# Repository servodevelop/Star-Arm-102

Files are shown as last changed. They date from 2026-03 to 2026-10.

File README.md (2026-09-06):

# Star Arm 102: Open-Source Robotic Arm Development Resources
[中文](README.zh.md)

## Ecosystem

Star-Arm-102 is the central repository for Fashion Star's Star Arm 102 robotic arm ecosystem, bringing together teleoperation, ROS 2, LeRobot integrations, and hardware resources.

- 🔗 [Star Arm 102 Series Hub](https://fashionstar.com.hk/robot-arm/star-arm-102/)
- 🐙 [Main Repo: Star-Arm-102](https://github.com/servodevelop/Star-Arm-102)

## Related Repositories

- [piper-mate](https://github.com/servodevelop/piper-mate) — Main repository for the PiPER-Mate robotic arm project and its teleoperation workflows.
- [lerobot](https://github.com/servodevelop/lerobot) — Fashion Star's LeRobot framework integration fork for robotic arm learning and teleoperation.
- [servo-canbus-sdk](https://github.com/servodevelop/servo-canbus-sdk) — CAN bus servo SDK with Python examples for Fashion Star CAN bus servos.
- [servo-uart-rs485-sdk](https://github.com/servodevelop/servo-uart-rs485-sdk) — UART/RS485 servo SDK with serial-bus examples and development tools.
- [Star Arm 102 Series Hub](https://fashionstar.com.hk/robot-arm/star-arm-102/) — Official series overview and product information.







---

## 📖 Project Overview

<p align="center">
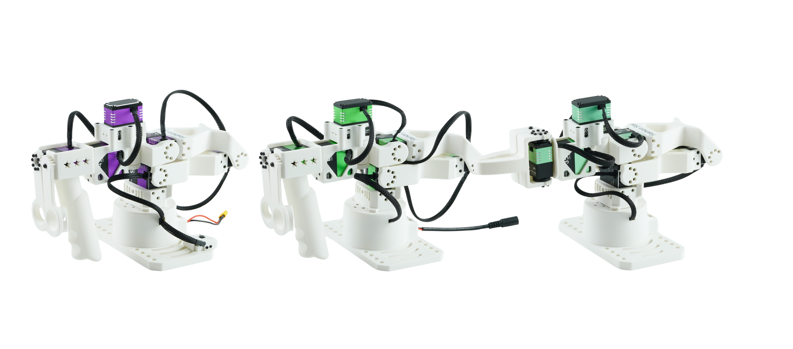
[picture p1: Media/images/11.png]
  
</p>

Star Arm 102 is an open-source 6+1 DOF leader–follower robotic arm system for teleoperation and robotics development. This repository brings together the code and resources needed to work with it, including Python SDK examples, ROS 2 Humble packages, LeRobot integrations, hardware files, and setup guides.

Use it to connect and control the arms, try supported software workflows, and build your own robotics applications.

Learn more about the full Star Arm 102 series:
[Star Arm 102 robot arm — series overview](https://fashionstar.com.hk/robot-arm/star-arm-102/)

## 🛒 Where to Buy
- [Star Arm 102-LD — LeRobot Certified Leader Arm](https://fashionstar.com.hk/store/product/star-arm-102-ld/)
- [Star Arm 102-HD — Pose-Holding Leader Arm](https://fashionstar.com.hk/store/product/star-arm-102-hd/)
- [Star Arm 102-FL — Follower Arm](https://fashionstar.com.hk/store/product/star-arm-102-fl/)

## 🔗 Related Links
- [Fashion Star Official Website](https://fashionstar.com.hk/)

### ✨ Key Features

- 🔓 **Open source · Low cost · Flexible access**

Fully open-source design lowers the barrier to learning and use.

Two access options are available: purchase a pre-assembled unit for immediate use, or print and assemble it yourself by preparing the printed parts and components. The DIY option is well suited for teaching and hands-on practice.

- ⚙️ **Well-designed robotic arm configuration**

6 active joints + 1 end effector.

The joint configuration strictly satisfies the Pieper criterion and supports analytical inverse kinematics. The algorithm is transparent, making it easy to teach and extend.

- 🔗 **LD model: highly compatible teleoperation leader arm**

Star Arm 102-LD can smoothly teleoperate the FL model in the same series.

It is also directly compatible with reBot and other robotic arms that have identical or similar kinematic configurations.

One leader arm can work with multiple arms, providing a smoother teleoperation experience across different systems.

- 🔒 **HD model: enhanced leader arm with one-button locking**

Star Arm 102-HD is an upcoming leader-arm model in the Star Arm 102 series.

Compared with the LD model, HD adds a one-button locking function: after the lock button is pressed, the leader arm holds its current pose and the follower arm enters the locked state at the same time; pressing the button again unlocks the system.

- 🕹️ **Multi-platform compatibility · Plug and play**

Supports direct teleoperation through the Python SDK.

Deeply compatible with the LeRobot and ROS 2 ecosystems.

Covers the full workflow of real robotic applications: data collection → simulation → model training → physical deployment.

- 📚 **Complete learning resources**

Provides tutorials, API documentation, and example code from beginner to advanced levels.

Suitable for university teaching, research experiments, and self-learning by individual developers.

---

## 🔧 Arm Specifications

| | Star Arm 102-HD | Star Arm 102-LD | Star Arm 102-FL |
|---|---|---|---|
| Arm span | 420mm | 420mm | 420mm |
| DOF | 6+1 | 6+1 | 6+1 |
| Repeatability | - | - | ±0.5mm |
| Suggested maximum payload | - | - | 500g |
| Joint range<br> | Joint 1: ±110°<br>Joint 2: 0°\~180°<br>Joint 3: 0°\~270°<br>Joint 4: ±90°<br>Joint 5: ±65°<br>Joint 6: ±150°<br>Handle: 0\~90° | Joint 1: ±110°<br>Joint 2: 0°\~180°<br>Joint 3: 0°\~270°<br>Joint 4: ±90°<br>Joint 5: ±65°<br>Joint 6: ±150°<br>Handle: 0\~90° | Joint 1: ±110°<br>Joint 2: 0°\~180°<br>Joint 3: 0°\~270°<br>Joint 4: ±90°<br>Joint 5: ±65°<br>Joint 6: ±150°<br>Gripper: 0\~90° |
| Servo configuration | Joints 1-4 (servo IDs 0-3): RP8-U45H-M;<br>Joint 5 (servo ID 4): RP8-U45H-M-C029;<br>Joint 6 and handle joint (servo IDs 5-6): RP8-U45H-M-C028; | Joints 1-4 (servo IDs 0-3): RA8-U01H-M;<br>Joint 5 (servo ID 4): RA8-U02H-M;<br>Joint 6 and handle joint (servo IDs 5-6): RA8-U03H-M; | Joints 1, 4, 7, and gripper joint (servo IDs 0, 3, 6): RA8-U35H-M;<br>Joints 2 and 3 (servo IDs 1-2): RX8-U50H-M;<br>Joint 5 (servo ID 4): RA8-U27H-M-C005;<br>Joint 6 (servo ID 5): RA8-U35H-M-C047; |
| Communication hub | UC-01 | UC-01 | UC-01 |
| Communication method | UART | UART | UART |
| Power supply | 12V10A / XT30 | 12V3A / DC5521 | 12V10A / XT30 |
| Accessories | Screws, threadlocker, woodworking clamps x2, spare PCB (UC01), DC power adapter cable (5.5×2.1mm connector), 200mm servo extension cable, USB-A to USB-C cable, mouse pad, base support | Screws, threadlocker, woodworking clamps x2, spare PCB (UC01), XT30 power adapter cable, 200mm servo extension cable, USB-A to USB-C cable, mouse pad, base support | Screws, threadlocker, woodworking clamps x2, spare PCB (UC01), DC power adapter cable (5.5×2.1mm connector), 200mm servo extension cable, USB-A to USB-C cable, mouse pad |
| Encoder | 12-bit magnetic encoder | 12-bit magnetic encoder | 12-bit magnetic encoder |
| Weight | 883g | 721g | 791g |
| Recommended operating temperature | 0-40°C | 0-40°C | 0-40°C |
| Button lock support | ✓ | × | - |
| LeRobot support | ✓ | ✓ | ✓ |
| ROS 2 support | ✓ | ✓ | ✓ |
| MoveIt support | - | - | ✓ |
| Gazebo support | - | - | ✓ |

---

## 🔧 Hardware Resources

<p align="center">
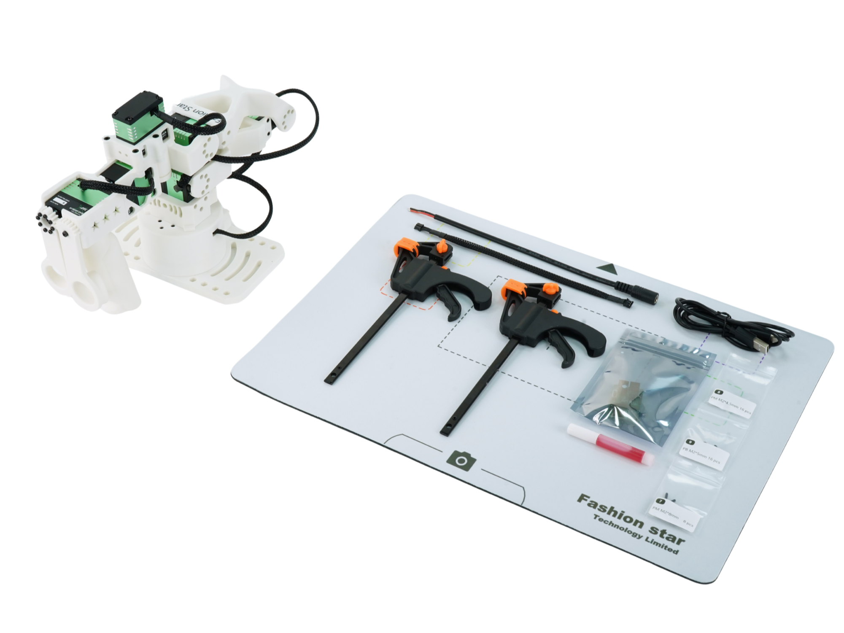
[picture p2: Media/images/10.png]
  
</p>

- [Parts List](./Hardware/README.md): view the complete parts list, quantities, and accessories

- [Engineering Drawings](./Hardware/cad/README.md): view assembly drawings and manufacturing drawings

- [Assembly Guide](./Hardware/assembly/README.md): view assembly sequence, notes, and reference images. This section is still being improved.

- [MakerWorld Models](https://makerworld.com.cn/zh/models/2366043-xing-bi-102-ld?from=search#profileId-2682765): download the 3D printable files for Star Arm 102-LD, which can be used to replace parts or assemble the robotic arm yourself

> The firmware and documentation for the Star Arm 102-HD lock-button board are located in the `Star-Arm-102-dev-main` project. The button board uses ID 7 by default. In host mode, it can directly send lock / unlock commands. In slave mode, it can be polled by the host as a simulated servo and returns 0.0° / 180.0° to indicate unlocked / locked states.

---

## 🚀 Quick Start

### Requirements

| Item | Requirement |
|---|---|
| Operating System | Ubuntu 22.04 |
| ROS Version | ROS 2 Humble |
| Hardware | StarArm 102 robotic arms (Leader/HD + Follower) |
| Driver | [CH340 USB Driver](https://www.wch.cn/downloads/CH341SER_EXE.html) |

### Installation

#### Method 1: Bare-metal teleoperation with Python SDK (recommended for beginners)

```bash
# 1. Install dependencies
pip install pyserial fashionstar-uart-sdk

# 2. Run the program
sudo chmod 777 /dev/ttyUSB*
python3 ./Python_SDK/stararm102_ro.py
```

#### Method 2: ROS 2 Humble

```bash
# See ROS2_HUMBLE/README.md for configuration instructions
```

#### Method 3: LeRobot framework

```bash
# See Lerobot/README.md for configuration instructions
```

---

## 📂 Project Structure

<details>
<summary>Expand to view the project structure</summary>

```text
Star-Arm-102/
|-- .gitignore                               # Git ignore rules
|-- Hardware/                                # Hardware resources
|   |-- assembly/                            # Assembly instructions
|   |-- cad/                                 # CAD models and engineering drawing documentation
|   |-- parts/                               # Parts list and BOM
|   `-- README.md                            # Hardware overview
|-- Lerobot/                                 # LeRobot framework control workflow
|   |-- lerobot-robot-stararm102/            # Follower robot configuration
|   |-- lerobot-teleoperator-stararm102/     # Leader teleoperator
|   |-- lerobot-stararm102/                  # New StarArm102 LeRobot plugin package
|   |   |-- examples/                        # State reading and leader-follower replay examples
|   |   |-- lerobot_teleoperator_stararm102/ # HD/FL device configuration and driver implementation
|   |   |-- pyproject.toml                   # Python package configuration
|   |   `-- README.md                        # Plugin package usage instructions
|   |-- media/                               # Media assets for LeRobot documentation
|   |-- stararm102_en.md                     # LeRobot usage documentation in English
|   |-- stararm102.md                        # LeRobot usage documentation
|   `-- README.md                            # Usage steps
|-- Media/                                   # Image assets used by README files and documentation
|   |-- images/                              # Image assets
|   `-- video/                               # Video assets
|-- Python_SDK/                              # Python SDK control workflow
|   |-- stararm102_ro.py                     # Leader-follower control program with LD/HD configuration support
|   |-- stararm102_ro_hover.py               # Hover / lock control example program
|   `-- PYTHON_SDK_GUIDE.md                  # Detailed Python SDK usage documentation
|-- ROS2_HUMBLE/                             # ROS 2 control workflow
|   `-- src/
|       |-- arm_moveit_read/                 # Pose reading node
|       |-- arm_moveit_write/                # Pose writing node
|       |-- arm_read_pose/                   # Real-time pose reading
|       |-- robo_driver/                     # Robotic arm hardware driver node
|       |-- robo_interfaces/                 # Custom ROS 2 interfaces
|       |-- ros2_bag_recorder/               # Demonstration trajectory recording
|       |-- stararm102_controller/           # Robotic arm controller
|       |-- stararm102_description/          # Robotic arm URDF model description
|       |-- stararm102_gazebo/               # Gazebo simulation environment configuration
|       `-- stararm102_moveit_config/        # MoveIt 2 motion planning configuration
|-- README.md                                # English README (default)
`-- README.zh.md                             # Chinese README
```

</details>

---

## 🎯 Control Method Comparison

| Feature | Python SDK | ROS 2 Humble | LeRobot |
|---|---|---|---|
| Difficulty | ⭐ Easy | ⭐⭐⭐ Medium | ⭐⭐⭐⭐⭐ Advanced |
| Real-time performance | ⭐⭐⭐⭐⭐ | ⭐⭐⭐ | ⭐⭐⭐ |
| Extensibility | ⭐⭐ | ⭐⭐⭐⭐⭐ | ⭐⭐⭐⭐ |
| Use cases | Quick testing, teaching | Robotic system integration | AI training, research |

---

## 🔧 Hardware Connection

### Connection Topology

```bash
                    ┌─────────────────┐
                    │                 │
                    │    Computer     │
                    │ (Ubuntu 22.04)  │
                    └────────┬────────┘
                             │
              ┌──────────────┼──────────────┐
             USB                           USB
              │                             │
       ┌──────┴──────┐               ┌──────┴────────┐
       │             │               │               │
       │ Leader Arm  │               │ Follower Arm  │
       │(StarArm 102)│               │ (StarArm 102) │
       └─────────────┘               └───────────────┘
```

### Device Detection

```bash
# List all USB devices
lsusb

# List serial devices
ls -l /dev/ttyUSB*

# Grant permissions
sudo chmod 777 /dev/ttyUSB*
```

---

## 📊 Joint Mapping

The StarArm 102 robotic arm has 7 joints in total: 6 DOF + 1 rotary gripper. The joint numbers used in the documentation start from 1, while the servo IDs used in code and on the servo bus start from 0. The mapping is shown below:

| Functional joint | Code joint name | Servo ID | Angle range | Description |
|---|---|---|---|---|
| Joint 1 | Joint1 | 0 | -110° ~ 110° | Base rotation |
| Joint 2 | Joint2 | 1 | 0° ~ 180° | Shoulder pitch |
| Joint 3 | Joint3 | 2 | 0° ~ 270° | Elbow pitch |
| Joint 4 | Joint4 | 3 | -90° ~ 90° | Wrist rotation |
| Joint 5 | Joint5 | 4 | -65° ~ 65° | Wrist yaw |
| Joint 6 | Joint6 | 5 | -150° ~ 150° | Wrist rotation |
| Gripper / Joint 7 | Gripper (joint7_left) | 6 | 0° ~ 90° | Rotary gripper |

> 📝 **Note**: The rotary gripper is controlled through `joint7_left`. `joint7_right` is a coupled joint and automatically synchronizes in the opposite direction.

---

## ⚠️ Safety Notes

1. **Check before operation**: Make sure there are no obstacles around the robotic arm and that the workspace is safe.
2. **Emergency stop**: Press `Ctrl+C` while the program is running to stop immediately.
3. **Joint limits**: Safety angle limits are configured automatically to prevent out-of-range motion.
4. **Power management**: Ensure stable power supply to avoid voltage fluctuations.

---

## 🐛 Troubleshooting

### Common Issues

**Q1: Cannot find `/dev/ttyUSB0`?**

```bash
# Check USB devices
ls -l /dev/ttyUSB*

# Check USB device information
lsusb

# View serial port logs
sudo dmesg | grep ttyUSB

# If the device is occupied by brltty, remove it
sudo apt remove brltty

# Grant permissions
sudo chmod 777 /dev/ttyUSB*
```

**Q2: Serial connection failed?**

- Check whether the USB cable is loose.
- Confirm that the robotic arm is powered on.
- Try a different USB port.
- Check whether the driver is installed correctly.

**Q3: Control frequency is too low?**

- Check whether serial communication is working properly.
- Reduce the load from other running programs.
- Use a USB 3.0 port for better performance.

**Q4: Robotic arm connection failed?**

- Check whether the USB cable is loose.
- Confirm that the robotic arm is powered on.
- Check the servo communication status.
- Try a different USB port.

---

## 📖 Detailed Documentation

Choose the control method you need and read the corresponding documentation:

- 📘 **[Python SDK Documentation](./Python_SDK/PYTHON_SDK_GUIDE.md)** - Recommended, the easiest way to get started
- 📗 **[ROS 2 Humble Documentation](./ROS2_HUMBLE/README.md)** - Suitable for robotic system integration
- 📙 **[LeRobot Documentation](./Lerobot/README.md)** - Suitable for AI training and research

## 📄 License

This project is open source under the [MIT License](LICENSE).

---

## 👥 Acknowledgements

- **Thanks to** FashionStar for hardware support and SDK resources.

---

## 🔗 Related Links

- [FashionStar Official Website](https://fashionstar.com.hk/)
- [Star Arm 102 series overview](https://fashionstar.com.hk/robot-arm/star-arm-102/)
- [LeRobot Framework](https://github.com/huggingface/lerobot)
- [ROS 2 Documentation](https://docs.ros.org/en/humble/)
- [MoveIt 2 Documentation](https://moveit.picknik.ai/humble/)

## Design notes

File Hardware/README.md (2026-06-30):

# Hardware

本目录用于存放 Star Arm 102 的硬件相关资料，方便大家查阅零件清单、查看 CAD 图纸以及参考装配说明。

## 目录说明

- [parts/](./parts/): 各零件STEP 与 BOM
- [cad/](./cad/README.md): CAD工程图纸
- [assembly/](./assembly/README.md): 装配说明与装配参考资料

## 入口指引

### 1. 零件清单

如果你想了解这台机械臂需要哪些零件、每种零件需要多少数量，可以先查看 `Star Arm 102-LD_BOM.xlsx`。下面整理了两份便于在 GitHub 直接浏览的清单：主体物料表与配件清单表。

#### 主体物料表

| 序号 | 物料名称 | 备注 | 数量 |
|:---|:---|:---|:---|
| 1 | 3D打印件（star102底座下） | - | 1 |
| 2 | 3D打印件（star102底座上） | - | 1 |
| 3 | 3D打印件（star102_link1） | - | 1 |
| 4 | 3D打印件（star102_link2） | - | 1 |
| 5 | 3D打印件（star102_link3） | - | 1 |
| 6 | 3D打印件（star102_link4） | - | 1 |
| 7 | 3D打印件（star102_link5） | - | 1 |
| 8 | 3D打印件（star102_link6手柄） | - | 1 |
| 9 | 3D打印件（star102_手柄） | - | 1 |
| 10 | 3D打印件（star102_指环左） | - | 1 |
| 11 | 3D打印件（star102_指环右） | - | 1 |
| 12 | PCBD | UC-01 0.75平方5.5x2.1母头 | 1 |
| 13 | 线材 | L=120 mm 黑色编织线 | 5 |
| 14 | 线材 | L=200 mm 黑色编织线 | 2 |
| 15 | 螺丝 | HSCS M3*10 12.9级内六角圆柱头螺钉 | 1 |
| 16 | 螺丝 | M3*22 黑色内六角 | 4 |
| 17 | 螺丝 | M3*8加硬包黑十字槽螺杆 | 1 |
| 18 | 螺丝 | PB2.0*5 自攻十字槽加硬包黑沉头螺杆 | 39 |
| 19 | 螺丝 | M2*4.5 预点胶十字槽螺杆黑色沉头 | 35 |
| 20 | 螺丝 | M2*8 黑色内六角 | 16 |
| 21 | 螺丝 | M3*8自攻十字槽螺杆 | 2 |
| 22 | 螺母 | M3防松螺母 黑色 | 5 |
| 23 | 垫片 | M3不锈钢 | 1 |
| 24 | RA8-U01H-M | - | 4 |
| 25 | RA8-U02H-M | - | 1 |
| 26 | RA8-U03H-M | - | 2 |

#### 配件清单表

| 序号 | 物料名称 | 备注 | 数量 |
|:---|:---|:---|:---|
| 27 | 螺丝胶 | - | 1 |
| 28 | 木工夹 | - | 2 |
| 29 | 备用PCBD | UC-01 | 1 |
| 30 | 备用电源线 | XT30 电源转接线, 0.25米 | 1 |
| 31 | 数据线 | USB转type c数据线 | 1 |
| 32 | 线材 | PH-3Y 双头反向60芯 0.08 黑色硅胶排线 L=200 mm 黑色编织线 | 1 |
| 33 | 7号螺丝套装 | M2*8 黑色内六角 8pcs | 1 |
| 34 | 8号螺丝套装 | M2*4.5 预点胶十字槽螺杆黑色沉头 16pcs | 1 |
| 35 | 9号螺丝套装 | PB2.0*5 自攻十字槽加硬包黑沉头螺杆 16pcs | 1 |
| 36 | 鼠标垫 | - | 1 |

- [MakerWorld Models](https://makerworld.com.cn/zh/models/2366043-xing-bi-102-ld?from=search#profileId-2682765): 此处可以下载Star Arm 102-LD的3D打印文件，自行替换或者组装机械臂

### 2. 开放 STEP 文件

`parts/` 目录中提供了部分可编辑 STEP 文件，方便用户根据自己的安装场景、底座形状或手型进行二次修改。用户可以使用常见 CAD 软件打开这些文件，调整后再导出 STL 或其他格式进行 3D 打印。

| 文件 | 说明 | 适用场景 |
|:---|:---|:---|
| [First-Person_Camera_Mount_Base.STEP](./parts/First-Person_Camera_Mount_Base.STEP) | 第一视角相机固定底座 | 安装第一视角相机，可根据相机尺寸或安装位置调整 |
| [First-Person_Camera_Mount_Top_Cover.STEP](./parts/First-Person_Camera_Mount_Top_Cover.STEP) | 第一视角相机固定上盖 | 与相机固定底座配合使用，用于固定相机 |
| [StarArm102_Base_Bottom.STEP](./parts/StarArm102_Base_Bottom.STEP) | 机械臂底座下半部分 | 可根据实际安装方式修改底部结构 |
| [StarArm102_Base_Top.STEP](./parts/StarArm102_Base_Top.STEP) | 机械臂底座上半部分 | 可装配到修改后的StarArm102_Base_Bottom上检查是否有干涉 |
| [StarArm102_Base_Support.STEP](./parts/StarArm102_Base_Support.STEP) | 机械臂底托 | 用于归位时放置手柄，可自行打印 |
| [StarArm102_Handle.STEP](./parts/StarArm102_Handle.STEP) | 手柄 | 可根据用户手掌大小和握持习惯微调 |
| [StarArm102_Finger_Ring_Left.STEP](./parts/StarArm102_Finger_Ring_Left.STEP) | 左指环 | 可根据左手手指尺寸调整佩戴手感 |
| [StarArm102_Finger_Ring_Right.STEP](./parts/StarArm102_Finger_Ring_Right.STEP) | 右指环 | 可根据右手手指尺寸调整佩戴手感 |

> 建议在修改前保留原始文件备份；如果调整了相机固定件、底座或手柄结构，请在打印前检查装配间隙、螺丝孔位和运动空间，避免与机械臂运动范围发生干涉。

### 3. CAD 与工程图纸

如果你想查看整机结构、核对尺寸，可以进入 [cad/README.md](./cad/README.md)。

### 4. 装配说明

装配说明正在制作中，后续可以自购买散件套装，组装自己的机械臂。

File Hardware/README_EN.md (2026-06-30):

# Hardware

This directory stores hardware-related resources for Star Arm 102, making it easy to check the parts list, view CAD drawings, and refer to assembly documentation.

## Directory Overview

- [parts/](./parts/): STEP files for parts and BOM
- [cad/](./cad/README.md): CAD engineering drawings
- [assembly/](./assembly/README.md): Assembly instructions and reference materials

## Navigation

### 1. Parts List

If you want to understand which parts are required for this robotic arm and how many of each part are needed, start with `Star Arm 102-LD_BOM.xlsx`. The following two tables are provided for convenient browsing on GitHub: the main BOM and the accessory list.

#### Main BOM

| No. | Item | Notes | Qty |
|:---|:---|:---|:---|
| 1 | 3D-printed part (star102 base bottom) | - | 1 |
| 2 | 3D-printed part (star102 base top) | - | 1 |
| 3 | 3D-printed part (star102_link1) | - | 1 |
| 4 | 3D-printed part (star102_link2) | - | 1 |
| 5 | 3D-printed part (star102_link3) | - | 1 |
| 6 | 3D-printed part (star102_link4) | - | 1 |
| 7 | 3D-printed part (star102_link5) | - | 1 |
| 8 | 3D-printed part (star102_link6 handle) | - | 1 |
| 9 | 3D-printed part (star102 handle) | - | 1 |
| 10 | 3D-printed part (star102 left finger ring) | - | 1 |
| 11 | 3D-printed part (star102 right finger ring) | - | 1 |
| 12 | PCBD | UC-01, 0.75 mm² 5.5 x 2.1 female connector | 1 |
| 13 | Cable | L=120 mm black braided cable | 5 |
| 14 | Cable | L=200 mm black braided cable | 2 |
| 15 | Screw | HSCS M3*10, grade 12.9 hex socket head cap screw | 1 |
| 16 | Screw | M3*22 black hex socket screw | 4 |
| 17 | Screw | M3*8 hardened black Phillips screw | 1 |
| 18 | Screw | PB2.0*5 hardened black countersunk self-tapping Phillips screw | 39 |
| 19 | Screw | M2*4.5 pre-applied threadlocker black countersunk Phillips screw | 35 |
| 20 | Screw | M2*8 black hex socket screw | 16 |
| 21 | Screw | M3*8 self-tapping Phillips screw | 2 |
| 22 | Nut | M3 black locknut | 5 |
| 23 | Washer | M3 stainless steel | 1 |
| 24 | RA8-U01H-M | - | 4 |
| 25 | RA8-U02H-M | - | 1 |
| 26 | RA8-U03H-M | - | 2 |

#### Accessory List

| No. | Item | Notes | Qty |
|:---|:---|:---|:---|
| 27 | Threadlocker | - | 1 |
| 28 | Woodworking clamp | - | 2 |
| 29 | Spare PCBD | UC-01 | 1 |
| 30 | Spare power cable | XT30 power adapter cable, 0.25 m | 1 |
| 31 | Data cable | USB to Type-C data cable | 1 |
| 32 | Cable | PH-3Y dual-end reverse 60-core 0.08 black silicone ribbon cable, L=200 mm black braided cable | 1 |
| 33 | No. 7 screw kit | M2*8 black hex socket screw, 8 pcs | 1 |
| 34 | No. 8 screw kit | M2*4.5 pre-applied threadlocker black countersunk Phillips screw, 16 pcs | 1 |
| 35 | No. 9 screw kit | PB2.0*5 hardened black countersunk self-tapping Phillips screw, 16 pcs | 1 |
| 36 | Mouse pad | - | 1 |

- [MakerWorld Models](https://makerworld.com.cn/zh/models/2366043-xing-bi-102-ld?from=search#profileId-2682765): Download the 3D-printable files for Star Arm 102-LD here. You can use them to replace parts or assemble the robotic arm yourself.

### 2. Open STEP Files

The `parts/` directory provides several editable STEP files. Users can modify them for their own mounting scenario, base shape, or hand size. Open these files with common CAD software, adjust them as needed, and then export STL or another format for 3D printing.

| File | Description | Use Case |
|:---|:---|:---|
| [First-Person_Camera_Mount_Base.STEP](./parts/First-Person_Camera_Mount_Base.STEP) | First-person camera mount base | Mounts the first-person camera. Adjust it for the camera size or mounting position. |
| [First-Person_Camera_Mount_Top_Cover.STEP](./parts/First-Person_Camera_Mount_Top_Cover.STEP) | First-person camera mount top cover | Works with the camera mount base to secure the camera. |
| [StarArm102_Base_Bottom.STEP](./parts/StarArm102_Base_Bottom.STEP) | Lower half of the robotic arm base | Modify the bottom structure for the actual mounting method. |
| [StarArm102_Base_Top.STEP](./parts/StarArm102_Base_Top.STEP) | Upper half of the robotic arm base | Assemble it with the modified StarArm102_Base_Bottom to check for interference. |
| [StarArm102_Base_Support.STEP](./parts/StarArm102_Base_Support.STEP) | Robotic arm base support | Used to place the handle when homing; users can print it themselves. |
| [StarArm102_Handle.STEP](./parts/StarArm102_Handle.STEP) | Handle | Adjust it for the user's palm size and grip preference. |
| [StarArm102_Finger_Ring_Left.STEP](./parts/StarArm102_Finger_Ring_Left.STEP) | Left finger ring | Adjust it for the user's left-hand finger size and comfort. |
| [StarArm102_Finger_Ring_Right.STEP](./parts/StarArm102_Finger_Ring_Right.STEP) | Right finger ring | Adjust it for the user's right-hand finger size and comfort. |

> Keep a backup of the original files before editing. If you modify the camera mounts, base, or handle structure, check assembly clearance, screw-hole positions, and motion space before printing to avoid interference with the robotic arm's range of motion.

### 3. CAD and Engineering Drawings

If you want to view the overall structure or check dimensions, go to [cad/README.md](./cad/README.md).

### 4. Assembly Instructions

Assembly instructions are still being prepared. In the future, users will be able to purchase a parts kit and assemble their own robotic arm.

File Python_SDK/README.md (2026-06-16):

# Python SDK - StarArm 102 机械臂控制





---

## 📖 简介

Python SDK 是 StarArm 102 机械臂的 Python 控制接口，提供简单易用的 Python API 用于机械臂的实时控制。该 SDK 支持主从遥操作模式，可通过 UART 串口直接控制机械臂舵机。

### ✨ 核心特性

- 🤖 **主从遥操作**：支持 Leader 机械臂实时控制 Follower 机械臂
- ⚡ **高实时性**：支持 100Hz+ 的控制频率
- 🎯 **多关节控制**：同时控制 7 个舵机关节
- 📊 **性能监控**：实时显示控制频率
- 🔧 **简单易用**：基于 Python，无需复杂配置

---

## 🚀 快速开始

### 环境要求

| 项目 | 要求 |
|---|---|
| 操作系统 | Ubuntu 22.04 |
| Python 版本 | Python 3.8+ |
| 硬件设备 | StarArm 102 机械臂 (Leader + Follower) |
| 串口设备 | 2个 USB 转串口设备 |

### 安装依赖

```bash
# 安装 Python 依赖包
pip install pyserial fashionstar-uart-sdk
```

### 硬件连接

1. **连接 Leader 机械臂**：
   - 使用 USB 线将 Leader 机械臂连接到计算机
   - 确认端口号（默认为 `/dev/ttyUSB0`）

2. **连接 Follower 机械臂**：
   - 使用 USB 线将 Follower 机械臂连接到计算机
   - 确认端口号（默认为 `/dev/ttyUSB1`）

3. **检查 USB 设备**：

```bash
# 查看所有串口设备
ls -l /dev/ttyUSB*

# 如果没有权限，赋予读写权限
sudo chmod 777 /dev/ttyUSB*
```

---

## 📂 项目结构

```bash
Python_SDK/
├── stararm102_ro.py       # 主从控制程序
└── README.md              # 本文档
```

---

## 💻 使用说明

### 基本使用

#### 1. 配置串口参数

编辑 `stararm102_ro.py` 文件，修改以下参数：

```python
SERVO_BAUDRATE = 1000000          # 舵机通信波特率
LEADER_PORT_NAME = "/dev/ttyUSB0" # Leader 机械臂端口号
FOLLOWER_PORT_NAME_Arr = ["/dev/ttyUSB1"]  # follower端口号
```

#### 2. 运行主从控制程序

```bash
# 赋予 USB 设备权限
sudo chmod 777 /dev/ttyUSB*

# 运行控制程序
python3 stararm102_ro.py
```

#### 3. 程序功能

程序启动后，将执行以下操作：

1. **初始化串口连接**：
   - 建立 Leader 机械臂的 UART 连接
   - 建立 Follower 机械臂的 UART 连接

2. **读取 Leader 状态**：
   - 实时读取 Leader 机械臂各关节角度
   - 支持 7 个舵机（ID: 0-6）

3. **控制 Follower 运动**：
   - 将 Leader 关节角度转换为 Follower 控制指令
   - 通过多圈角度间隔控制方式发送指令

4. **性能监控**：
   - 每秒显示当前运行频率（Hz）
   - 控制频率通常在 200Hz 左右

#### 4. 停止程序

按 `Ctrl+C` 终止程序运行

---

## 🔧 API 说明

### 主要函数

#### `main(args=None)`

主控制函数

**功能**：

- 初始化 Leader 和 Follower 串口连接
- 实时读取 Leader 关节角度
- 控制 Follower 跟随 Leader 运动
- 显示运行频率

**参数**：无

### 舵机控制参数

| 参数 | 值 | 说明 |
|---|-----|---|
| `SERVO_BAUDRATE` | 1000000 | 舵机通信波特率 |
| `LEADER_PORT_NAME` | /dev/ttyUSB0 | Leader 端口号 |
| `FOLLOWER_PORT_NAME` | /dev/ttyUSB1 | Follower 端口号 |
| `servo_ids` | [0,1,2,3,4,5,6] | 舵机 ID 列表 |

---

## 📊 控制流程

```bash
┌─────────────┐
│  Leader     │
│  机械臂      │
└──────┬──────┘
       │ 读取角度
       ▼
┌──────────────────┐
│   UART 串口通信   │
│ (/dev/ttyUSB0)   │
└──────┬───────────┘
       │
       ▼
┌──────────────────┐
│  Python 控制程序  │
│  - 数据处理       │
│  - 角度转换       │
└──────┬───────────┘
       │ 发送指令
       ▼
┌──────────────────┐
│   UART 串口通信   │
│ (/dev/ttyUSB1)   │
└──────┬───────────┘
       │
       ▼
┌─────────────┐
│  Follower   │
│  机械臂      │
└─────────────┘
```

---

## 🛡️ 安全注意事项

1. **操作前检查**：
   - 确保 USB 连接稳定
   - 确认机械臂周围无障碍物
   - 检查电源供电是否正常

2. **急停控制**：
   - 按 `Ctrl+C` 立即停止程序
   - 如遇异常，拔掉 USB 线断开连接

3. **关节限制**：
   - 确保 Leader 机械臂在安全角度范围内操作
   - 避免快速大幅度移动

4. **电源管理**：
   - 使用稳定的 12V 电源
   - 避免电压波动

---

## 🐛 故障排除

### 常见问题

**Q1: 找不到 `/dev/ttyUSB0` 设备？**

```bash
# 检查 USB 设备
ls -l /dev/ttyUSB*

# 检查 USB 设备信息
lsusb

# 查看串口日志
sudo dmesg | grep ttyUSB

# 如果被 brltty 占用，卸载它
sudo apt remove brltty

# 赋予权限
sudo chmod 777 /dev/ttyUSB*
```

**Q2: 串口连接失败？**

- 检查 USB 线是否松动
- 确认端口号是否正确
- 尝试更换 USB 端口
- 检查驱动是否正常安装

**Q3: 控制频率过低？**

- 检查串口通信是否正常
- 减少其他程序运行负载
- 使用 USB 3.0 端口以提高速度

**Q4: Follower 机械臂不跟随 Leader？**

- 检查 Follower 端口号配置
- 确认舵机 ID 设置正确
- 检查串口通信波特率

---

## 📖 详细文档

- [主项目 README](../README.md) - 项目总览
- [ROS2 HUMBLE 使用文档](../ROS2_HUMBLE/README.md) - ROS2 控制方式
- [Lerobot 使用文档](../Lerobot/README.md) - Lerobot 框架集成

---

## 🔗 相关链接

- [FashionStar UART SDK](https://github.com/servodevelop/servo-uart-rs485-sdk/)
- [华馨京科技官网](https://fashionrobo.com/)

---

## 📄 许可证

本项目基于 [MIT License](../LICENSE) 开源。

---

## 👥 致谢

- **感谢**：华馨京科技提供硬件支持和 SDK

---

**祝您使用愉快！如有问题，欢迎提交 Issue。**

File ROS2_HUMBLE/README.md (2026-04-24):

# StarArm102 机械臂 - ROS2 MoveIt 使用教程
## StarArm102 Manipulator - ROS2 MoveIt Guide

<div align="center">
  StarArm102 Robotic Arm StarArm102
</div>

---

## 📋 目录

- [环境依赖](#环境依赖-dependent-environment)
- [安装指南](#安装指南-installation-guide)
- [功能包说明](#功能包说明-package-description)
- [MoveIt2 快速开始](#moveit2-快速开始-moveit2-quick-start)
  - [使用虚拟机械臂](#使用虚拟机械臂-using-virtual-robotic-arm)
  - [使用真实的机械臂](#使用真实的机械臂-using-real-robotic-arm)
  - [手臂末端位姿读写示例](#手臂末端位姿读写示例-end-effector-pose-readwrite-demo)
  - [位姿话题发送节点示例](#位姿话题发送节点示例-position-and-orientation-topic-sending-node-demo)
  - [MoveIt2-Gazebo 仿真](#moveit2-gazebo-仿真-moveit2-gazebo-simulation)
- [机械臂示教模式](#机械臂示教模式-teaching-mode)
- [常见问题](#常见问题-faq)

---

## 🔧 环境依赖

### 系统要求

```bash
No LSB modules are available.

Distributor ID: Ubuntu
Description:    Ubuntu 22.04.5 LTS
Release:        22.04
Codename:       Jammy
ROS2:           Humble
```

---

## 📦 安装指南

### 1️⃣ 安装 ROS2 Humble

**中文指南：**
[ROS2 Humble 安装指南](https://wiki.seeedstudio.com/cn/install_ros2_humble/)

**English Guide：**
[ROS2 Humble Installation](https://wiki.seeedstudio.com/install_ros2_humble/)

### 2️⃣ 安装 MoveIt2

```bash
sudo apt install ros-humble-moveit*
```

### 3️⃣ 安装舵机 SDK 库

```bash
sudo pip install pyserial
sudo pip install fashionstar-uart-sdk
```

### 4️⃣ 克隆 StarArm102 功能包

```bash
cd ~/
git clone https://github.com/servodevelop/Star-Arm-102.git
cd ~/Star-Arm-102/ROS2_HUMBLE
colcon build
echo "source ~/Star-Arm-102/ROS2_HUMBLE/install/setup.bash" >> ~/.bashrc
source ~/.bashrc
```

> [!NOTE]
> 编译完成后，请执行 `source` 命令以使环境变量生效。
> After compilation, run `source` command to make environment variables take effect.

---

## 📦 功能包说明

| 功能包 | 说明 |
|---|---|
| `robo_driver` | 机械臂硬件驱动节点，负责与舵机通信 |
| `stararm102_description` | 机械臂URDF模型描述文件 |
| `stararm102_gazebo` | Gazebo仿真环境配置 |
| `stararm102_moveit_config` | MoveIt2运动规划配置 |
| `stararm102_controller` | 机械臂控制器节点 |
| `arm_moveit_read` | 位姿读取节点示例 |
| `arm_moveit_write` | 位姿写入节点示例 |
| `arm_read_pose` | 实时位姿读取节点 |
| `ros2_bag_recorder` | 示教轨迹录制与重播 |
| `robo_interfaces` | 自定义ROS2接口定义 |

---

## 🚀 MoveIt2 快速开始

### 🎮 使用虚拟机械臂

启动 RViz2 进行虚拟机械臂的路径规划和可视化控制。

**启动命令：**

```bash
ros2 launch stararm102_moveit_config demo.launch.py
```

启动后，您可以在 RViz2 界面中：

- 使用 **Motion Planning** 面板进行路径规划
- 拖动 **交互标记** 进行末端执行器定位
- 选择 **Planning Group** 来控制不同关节组
- 点击 **Plan** 查看规划路径
- 点击 **Execute** 执行规划轨迹

---

### 🦾 使用真实的机械臂

连接真实机械臂并进行实际控制。

**终端 1：启动手臂硬件驱动**

> [!IMPORTANT]
> 启动驱动后，手臂会移动到零位，请确保周围无障碍物。
> The arm will move to zero position after starting the driver. Ensure there are no obstacles nearby.

```bash
ros2 launch stararm102_moveit_config driver.launch.py
```

> [!TIP]
>
> - 如果serial出现问题可以运行
>
> ```bash
> sudo apt install --reinstall python3-serial
> ```

**终端 2**

**：启动 MoveIt2**

```bash
ros2 launch stararm102_moveit_config actual_robot_demo.launch.py
```

✅ 到此可实现虚拟机械臂控制真实机械臂的功能。
At this point, you can control the real robotic arm with the virtual robotic arm.

---

### 📐 手臂末端位姿读写示例

演示如何读取和写入机械臂末端的位姿信息。

**终端 3：启动末端位姿读写示例**

```bash
ros2 launch stararm102_moveit_config moveit_write_read.launch.py
```

该示例会：
- 实时显示当前末端执行器的位姿（位置和姿态）
- 演示如何设置目标位姿并执行运动
- 输出关节角度和笛卡尔坐标信息

---

### 📡 位姿话题发送节点示例

通过 ROS2 话题发送目标位姿，控制机械臂运动。

**终端 4：启动位姿话题发送节点**

```bash
# 运行话题发布节点
ros2 run arm_moveit_write topic_publisher
```

该节点会持续发布目标位姿到话题，MoveIt2 接收后控制机械臂运动到目标位置。

---

### 🎯 MoveIt2-Gazebo 仿真机械臂例程

在 Gazebo 物理仿真环境中测试机械臂控制。

> [!TIP]
> - 在关闭 Gazebo 图形界面后，建议使用 `pkill -9 -f gazebo` 命令彻底关闭
> - 运行例程前，需要关闭其他所有正在运行的节点
> - `killall -9 gazebo gzserver gzclient ros2`

#### 安装 Gazebo

```bash
sudo apt install gazebo
sudo apt install ros-humble-moveit*
sudo apt install -y ros-humble-gazebo-ros-pkgs ros-humble-gazebo-ros
```

#### 终端 1：启动 Gazebo 图形界面

```bash
ros2 launch stararm102_gazebo stararm102_gazebo.launch.py
```

启动 Gazebo 后，您会看到 StarArm102 机械臂在仿真环境中。

#### 终端 2：启动 MoveIt2 界面

```bash
ros2 launch stararm102_moveit_config gazebo_demo.launch.py
```

✅ 现在您可以在 RViz2 中进行路径规划，机械臂将在 Gazebo 仿真环境中执行运动。

---

## 🎓 机械臂示教模式

记录并重放机械臂的运动轨迹。

> [!TIP]
> - 需要重新录制轨迹时，可删除 `record-test` 文件夹或新建记录文件夹（如 `record-test1`）
> - 示教模式下，手臂驱动器需要解锁

### 终端 1：启动手臂硬件驱动（示教模式）

```bash
ros2 run robo_driver driver --ros-args -p lock:='disable'
```

> [!IMPORTANT]
> 设置 `lock:='disable'` 参数可以解锁关节，允许手动拖动机械臂进行示教。
> Setting `lock:='disable'` unlocks the joints, allowing manual dragging for teaching.

### 终端 2：记录手臂轨迹

按下回车开始录制，再次按下回车结束录制。通过 `dataset` 参数指定保存路径。

```bash
ros2 run ros2_bag_recorder bag_recorder --ros-args -p dataset:=star/record-test
```

**操作步骤：**

1. 运行命令后，按 **Enter** 开始录制
2. 手动拖动机械臂到目标位置
3. 完成后按 **Enter** 结束录制
4. 轨迹数据会保存到 `star/record-test` 文件夹

```bash
ros2 bag play ./star/record-test
```

机械臂会按照记录的轨迹自动运动。

> [!TIP]
>
> - 如果路径位置已经存在可以尝试删除旧路径`rm -rf star/record-test`或者更换新的路径如`dataset:=star/record-test2`

---

## 📊 关节配置

StarArm102 采用 6自由度机械臂 + 旋转夹爪：

| 关节 | 类型 | 角度范围 | 说明 |
|---|---|---|---|
| Joint1 | revolute | -110° ~ 110° | 底座旋转 |
| Joint2 | revolute | 0° ~ 180° | 肩部俯仰 |
| Joint3 | revolute | 0° ~ 270° | 肘部俯仰 |
| Joint4 | revolute | -90° ~ 90° | 手腕旋转 |
| Joint5 | revolute | -65° ~ 65° | 手腕俯仰 |
| Joint6 | revolute | -150° ~ 150° | 手腕偏航 |
| joint7_left | revolute | 0° ~ 90° | 旋转夹爪（主动） |
| joint7_right | revolute | -90° ~ 0° | 旋转夹爪（联动） |

> 📝 **旋转夹爪说明**：`joint7_right` 为 mimic 关节，自动与 `joint7_left` 反向同步。

---

## ❓ 常见问题 / FAQ

### RViz2 界面闪烁问题

如果 RViz2 界面出现频闪，可以尝试以下命令：

```bash
export QT_AUTO_SCREEN_SCALE_FACTOR=0
```

然后重新启动 RViz2。

### Gazebo 无法启动

如果 Gazebo 启动失败，请先检查是否有残留进程：

```bash
killall -9 gazebo gzserver gzclient 2>/dev/null || true
```

然后重新运行启动命令。

### 编译错误

如果在编译过程中遇到错误，请确保：

1. 已安装所有依赖：`sudo apt install ros-humble-moveit*`
2. 已正确 source ROS2 环境：`source /opt/ros/humble/setup.bash`
3. 在正确的目录下编译：`cd ~/Star-Arm-102/ROS2_HUMBLE`

### 机械臂无法连接

如果机械臂无法连接，请检查：

1. USB 串口连接是否正常
2. 串口权限是否正确：`sudo chmod 666 /dev/ttyUSB0`
3. 舵机 SDK 是否已正确安装

### 示教轨迹重播不正常

如果示教轨迹重播时机械臂运动不正常：

1. 检查 URDF 配置是否正确
2. 确认 `joint7_left` 和 `joint7_right` 的 mimic 配置
3. 查看 joint_states 话题数据是否正确

---

## 📞 技术支持

如遇到问题，请访问：

- GitHub 仓库：[Star-Arm-102](https://github.com/servodevelop/Star-Arm-102)
- 提交 Issue 获取帮助

---

<div align="center">

**StarArm102 - 让机械臂控制更简单**

*StarArm102 - Making Robot Arm Control Simpler*

</div>

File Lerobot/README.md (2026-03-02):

# lerobot_StarArm102

## Getting Started

1. 下载lerobot仓库代码[github克隆lerobot](https://github.com/servodevelop/lerobot)

2. 根据[stararm102](./stararm102.md)文档进行操作

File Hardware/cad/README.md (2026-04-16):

# CAD 图纸与工程文件

本目录用于存放 Star Arm 102-LD 的 CAD 图纸与工程文件，方便查看结构设计、核对关键尺寸。

<p align="center">
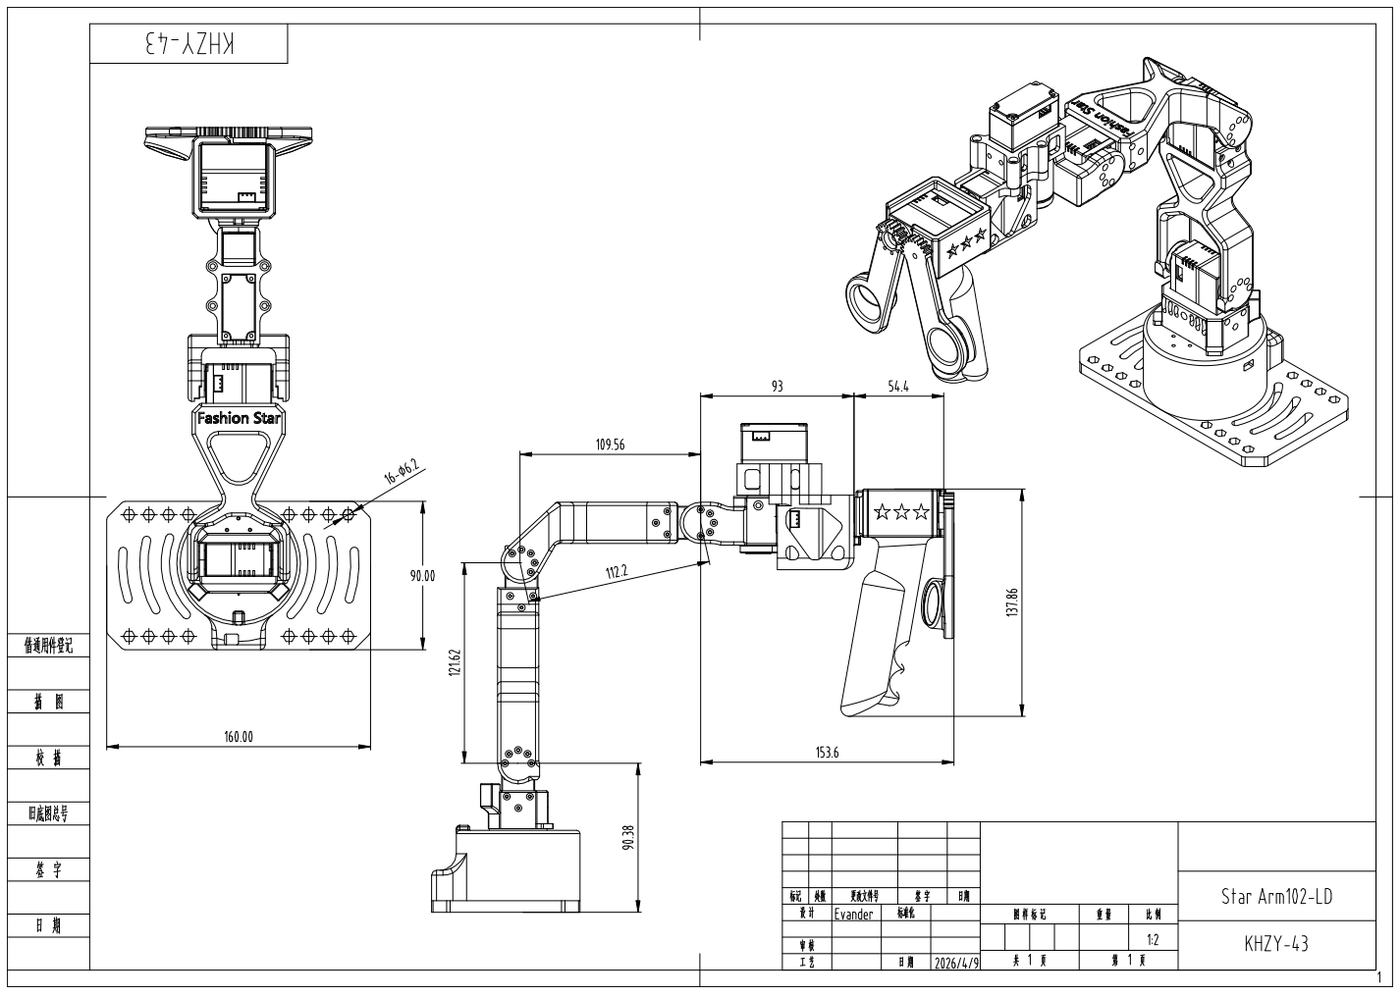
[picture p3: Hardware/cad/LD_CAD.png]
Star Arm 102-LD CAD preview
  
</p>

上图展示了 `Star Arm 102-LD` 的整体 CAD 图纸预览。

## 文件说明

- [Star Arm102-LD.pdf](./Star%20Arm102-LD.pdf)：用于快速查看与分享的 PDF 图纸
- [Star Arm102-LD.DWG](./Star%20Arm102-LD.DWG)：可在兼容 CAD 软件中继续编辑的原始工程文件
- [LD_CAD.png](./LD_CAD.png)：本 README 中使用的预览图片

## 使用建议

- 如果你只是想浏览图纸，建议优先使用 `PDF` 文件。
- 如果你需要编辑、复用或继续修改图纸，建议使用 `DWG` 文件。
- 在进行制造前，请确认 CAD 软件中的单位、比例和打印设置是否正确。

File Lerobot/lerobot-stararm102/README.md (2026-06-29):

# StarArm102 HD Teleoperator

This package contains a refactored StarArm102 / reBot Arm 102 integration with:

- a leader teleoperator: `stararm102_hd`
- a follower robot: `stararm102_fl`

## Install

```bash
pip install -e .
```

## Registered Teleoperator

- `stararm102_hd`

## Registered Robot

- `stararm102_fl`

## Quick Start

Typical workflow:

1. Calibrate the leader arm
2. Calibrate the follower arm
3. Test the leader example if needed
4. Start leader -> follower teleoperation
5. Optionally record leader logs and replay them into the follower for debugging

## Teleoperate

```bash
lerobot-teleoperate \
  --teleop.type=stararm102_hd \
  --teleop.id=stararm102_hd \
  --teleop.baudrate=1000000 \
  --teleop.port=/dev/ttyUSB0 \
  --robot.type=stararm102_fl \
  --robot.id=stararm102_fl \
  --robot.port=/dev/ttyUSB1 \
  --teleop.baudrate=1000000
```

This starts direct teleoperation from:

- leader: `/dev/ttyUSB0`
- follower: `/dev/ttyUSB1`

Enable the optional external button device:

```bash
lerobot-teleoperate \
  --fps=120 \
  --teleop.type=stararm102_hd \
  --teleop.id=stararm102_hd \
  --teleop.port=/dev/ttyUSB0 \
  --teleop.baudrate=1000000 \
  --teleop.button.enabled=false \
  --robot.type=stararm102_fl \
  --robot.id=stararm102_fl \
  --robot.port=/dev/ttyUSB1 \
  --teleop.baudrate=1000000
```

When `teleop.button.enabled=true`, servo id `7` is treated as an external button-like device:

- angle near `0.0` -> unlock leader
- angle near `180.0` -> lock leader and freeze teleop output

With button mode enabled:

- `locked=False`: leader motion is sent normally
- `locked=True`: the output action is frozen at the last unlocked action if `freeze_action_on_lock=true`

## Calibrate

Calibrate the leader arm:

```bash
lerobot-calibrate \
  --teleop.type=stararm102_hd \
  --teleop.id=stararm102_hd \
  --teleop.port=/dev/ttyUSB0 \
  --teleop.baudrate=1000000
```

This will:

- connect to the leader arm
- ask you to move the arm to its zero pose
- save the leader calibration file

Calibrate the follower arm:

```bash
lerobot-calibrate \
  --robot.type=stararm102_fl \
  --robot.id=stararm102_fl \
  --robot.port=/dev/ttyUSB1 \
  --robot.baudrate=1000000
```

This will:

- connect to the follower arm
- ask you to move the arm to its zero pose
- save the follower calibration file

If you want to rerun calibration from scratch, just execute the command again and follow the terminal prompts.

## Examples

Read only the button servo state:

```bash
python \
examples/read_button_state.py \
  --port=/dev/ttyUSB0 \
  --button-id=7
```

Use this when you only want to check whether the optional external button device is being read correctly.

Read leader joint state and write logs to `examples/leader.log`:

```bash
python \
examples/read_leader_state.py \
  --port=/dev/ttyUSB0 \
  --button-enabled
```

This example:

- connects to the leader
- prints `action`, `raw` joint angles, and `locked` state
- writes the same log stream to `examples/leader.log`

Replay recorded leader actions into the follower:

```bash
python \
examples/replay_leader_actions_to_follower.py \
  --port=/dev/ttyUSB1 \
  --input-log=examples/leader.log \
  --skip-locked \
  --interval=0.2
```

This example:

- reads `action={...}` records from `examples/leader.log`
- sends them to the follower as virtual leader input
- prints the sent action and the follower readback observation

It is useful for checking:

- whether follower communication is working
- whether `joint_directions` are correct
- whether `joint_ranges` are too tight or obviously incorrect
- whether the follower can approximately track the recorded leader motion

## Leader Config

`stararm102_hd_leader` currently supports these main config fields:

- `port`
- `baudrate`
- `joint_ids`
- `joint_directions`
- `joint_ranges`
- `button.enabled`
- `button.id`
- `button.trigger_threshold`
- `button.freeze_action_on_lock`
- `button.lock_on_connect`
- `excluded_lock_joints`

Default joint names are:

- `shoulder_pan`
- `shoulder_lift`
- `elbow_flex`
- `wrist_flex`
- `wrist_yaw`
- `wrist_roll`
- `gripper`

## Follower Config

`stararm102_fl` currently supports these main config fields:

- `port`
- `baudrate`
- `joint_ids`
- `joint_directions`
- `joint_ranges`

The follower does not include any button configuration. Its role is to receive action commands and drive the arm.

## Notes On Calibration And Ranges

- `joint_ranges` in config are still important as the structural per-joint limits for the current Stararm integration.
- Calibration is used to persist the arm-specific zero/range data, but it has not fully replaced config-level joint definitions.
- If no calibration file is found for the follower, the implementation falls back to the configured `joint_ranges`.
- During `lerobot-teleoperate`, if no valid calibration file is found, the device may prompt you to calibrate before teleoperation starts.

## Public API

The package exposes the StarArm teleoperator and follower implementations:

```python
from lerobot_teleoperator_stararm102_hd import (
    Stararm102HD,
    Stararm102HDConfig,
    Stararm102FL,
    Stararm102FLConfig,
)
```

## Add Camera

### find camera

```bash
lerobot-find-cameras opencv # or realsense for Intel Realsense cameras
```

```bash
lerobot-teleoperate \
  --teleop.type=stararm102_hd \
  --teleop.id=stararm102_hd \
  --teleop.port=/dev/ttyUSB0 \
  --teleop.baudrate=1000000 \
  --teleop.button.enabled=false \
  --robot.type=stararm102_fl \
  --robot.id=stararm102_fl \
  --robot.port=/dev/ttyUSB1 \
  --robot.baudrate=1000000 \
  --robot.cameras="{first_person: {type: opencv, index_or_path: 0, width: 640, height: 480, fps: 30}, third_person: {type: opencv, index_or_path: 2, width: 640, height: 480, fps: 30}}"
```

### record

```bash
rm -rf ./outputs/datasets
lerobot-record \
  --robot.type=stararm102_fl \
  --robot.id=stararm102_fl \
  --robot.port=/dev/ttyUSB1 \
  --robot.baudrate=1000000 \
  --robot.cameras="{first_person: {type: opencv, index_or_path: 0, width: 480, height: 640, fps: 30, rotation: ROTATE_270}, third_person: {type: opencv, index_or_path: 2, width: 640, height: 480, fps: 30}}" \
  --teleop.type=stararm102_hd \
  --teleop.id=stararm102_hd \
  --teleop.port=/dev/ttyUSB0 \
  --teleop.baudrate=1000000 \
  --dataset.repo_id=kian/stararm102_test \
  --dataset.single_task="Test recording" \
  --dataset.num_episodes=2 \
  --dataset.episode_time_s=600 \
  --dataset.reset_time_s=10 \
  --dataset.push_to_hub=false \
  --dataset.root=./outputs/datasets \
  --display_data=false
```

```bash
rm -rf ~/.cache/huggingface/lerobot/kian/stararm102_test
```

### Pick up a block

```bash
lerobot-record \
  --robot.type=stararm102_fl \
  --robot.id=stararm102_fl \
  --robot.port=/dev/ttyUSB1 \
  --robot.baudrate=1000000 \
  --robot.cameras="{first_person: {type: opencv, index_or_path: 0, width: 480, height: 640, fps: 20, rotation: ROTATE_270}, third_person: {type: opencv, index_or_path: 2, width: 640, height: 480, fps: 20}}" \
  --teleop.type=stararm102_hd \
  --teleop.id=stararm102_hd \
  --teleop.port=/dev/ttyUSB0 \
  --teleop.baudrate=1000000 \
  --dataset.repo_id=kian/stararm102_pick_block_v4 \
  --dataset.single_task="Pick up a block from the table and hold it steadily" \
  --dataset.num_episodes=200 \
  --dataset.episode_time_s=60 \
  --dataset.reset_time_s=3 \
  --dataset.push_to_hub=false \
  --dataset.root=./outputs/stararm102_pick_block_v4 \
  --display_data=true
```

### train

```bash
lerobot-train \
  --dataset.repo_id=kian/stararm102_pick_block_v3 \
  --dataset.root=./outputs/stararm102_pick_block_v3 \
  --policy.type=act \
  --policy.device=cuda \
  --policy.push_to_hub=false \
  --output_dir=./outputs/train_stararm102_pick_block_v3 \
  --batch_size=8 \
  --steps=5000 \
  --save_freq=200 \
  --eval_freq=0 \
  --num_workers=0
```

### test

```bash
rm -rf ./outputs/eval_stararm102_pick_block_v3_last_run1
LD_LIBRARY_PATH="$CONDA_PREFIX/lib:${LD_LIBRARY_PATH}" lerobot-record \
  --robot.type=stararm102_fl \
  --robot.id=stararm102_fl \
  --robot.port=/dev/ttyUSB1 \
  --robot.baudrate=1000000 \
  --robot.cameras="{first_person: {type: opencv, index_or_path: /dev/video0, width: 640, height: 480, fps: 30, backend: V4L2}, third_person: {type: opencv, index_or_path: /dev/video2, width: 640, height: 480, fps: 30, backend: V4L2}}" \
  --policy.path=./outputs/train_stararm102_pick_block_v3/checkpoints/last/pretrained_model \
  --dataset.repo_id=kian/eval_stararm102_pick_block_v3_last_run1 \
  --dataset.single_task="eval checkpoint last" \
  --dataset.num_episodes=1 \
  --dataset.episode_time_s=50 \
  --dataset.reset_time_s=8 \
  --dataset.push_to_hub=false \
  --dataset.root=./outputs/eval_stararm102_pick_block_v3_last_run1 \
  --display_data=true
```

## reBot Arm 102

## Teleoperate

```bash
lerobot-teleoperate \
  --robot.type=seeed_b601_dm_follower \
  --robot.port=/dev/ttyACM0 \
  --robot.id=follower1 \
  --robot.can_adapter=damiao \
  --robot.joint_directions='{"shoulder_pan":1,"shoulder_lift":1,"elbow_flex":1,"wrist_flex":1,"wrist_yaw":1,"wrist_roll":1,"gripper":10}' \
  --teleop.type=stararm102_hd \
  --teleop.port=/dev/ttyUSB0 \
  --teleop.id=stararm102_hd \
  --teleop.button.enabled=true
  ```

  `--teleop.button.enabled=false` if Leader is stararm102_LD

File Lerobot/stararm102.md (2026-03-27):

# 如何搭建具身智能LeRobot-starai系列机械臂并完成自定义抓取任务

## 产品介绍

1. **开源 & 便于二次开发**
   本系列舵机由[华馨京科技](https://fashionrobo.com/)提供，是一套开源、便于二次开发的6+1自由度机器臂解决方案。
2. **支持 LeRobot 平台集成**
   专为与 [LeRobot 平台](https://github.com/huggingface/lerobot) 集成而设计。该平台提供 PyTorch 模型、数据集与工具，面向现实机器人任务的模仿学习（包括数据采集、仿真、训练与部署）。
3. **丰富的学习资源**
   提供全面的开源学习资源，包括环境搭建，安装与调试与自定义夹取任务案例帮助用户快速上手并开发机器人应用。
4. **兼容 Nvidia 平台**
   支持通过 reComputer Mini J4012 Orin NX 16GB 平台进行部署。

## 特点内容

- **零组装**:  即刻上手｜一开箱即踏入AI时代。
- 6+1自由度结构设计，420mm臂展，赋予无限操作可能。
- 智能平行夹爪，最大开合66mm，模块化指尖，精准抓取不设限。

## 初始环境搭建

For Ubuntu X86:

- Ubuntu 22.04
- CUDA 12+
- Python 3.10
- Torch 2.6

## 安装与调试

### 安装LeRobot

需要根据你的 CUDA 版本安装 pytorch 和 torchvision 等环境。

1. 安装 Miniconda： 对于 Jetson：

    ```bash
    wget https://repo.anaconda.com/miniconda/Miniconda3-latest-Linux-aarch64.sh
    chmod +x Miniconda3-latest-Linux-aarch64.sh
    ./Miniconda3-latest-Linux-aarch64.sh
    source ~/.bashrc
    ```

    或者，对于 X86 Ubuntu 22.04：

    ```bash
    mkdir -p ~/miniconda3
    cd miniconda3
    wget https://repo.anaconda.com/miniconda/Miniconda3-latest-Linux-x86_64.sh -O ~/miniconda3/miniconda.sh
    bash ~/miniconda3/miniconda.sh -b -u -p ~/miniconda3
    rm ~/miniconda3/miniconda.sh
    source ~/miniconda3/bin/activate
    conda init --all
    ```

2. 创建并激活一个新的 conda 环境用于 LeRobot

    ```bash
    conda create -y -n lerobot python=3.10 && conda activate lerobot
    ```

3. 克隆 LeRobot 仓库：

    ```bash
    git clone https://github.com/servodevelop/lerobot.git
    ```

4. 使用 miniconda 时，在环境中安装 ffmpeg：

    ```bash
    conda install ffmpeg -c conda-forge
    ```

    这通常会为你的平台安装使用 libsvtav1 编码器编译的 ffmpeg 7.X。如果不支持 libsvtav1（可以通过 ffmpeg -encoders 查看支持的编码器），你可以：

    - 【适用于所有平台】显式安装 ffmpeg 7.X：

    ```bash
    conda install ffmpeg=7.1.1 -c conda-forge
    ```

5. 安装LeRobot：

    ```bash
    cd ~/lerobot && pip install -e .
    ```

    对于 Jetson Jetpack 设备（请确保在执行此步骤前按照[此链接教程](https://github.com/Seeed-Projects/reComputer-Jetson-for-Beginners/tree/main/3-Basic-Tools-and-Getting-Started/3.5-Pytorch)第 5 步安装了 Pytorch-gpu 和 Torchvision）：

    ```bash
    conda install -y -c conda-forge "opencv>=4.10.0.84"  # 通过 conda 安装 OpenCV 和其他依赖，仅适用于 Jetson Jetpack 6.0+
    conda remove opencv   # 卸载 OpenCV
    pip3 install opencv-python==4.10.0.84  # 使用 pip3 安装指定版本 OpenCV
    conda install -y -c conda-forge ffmpeg
    conda uninstall numpy
    pip3 install numpy==1.26.0  # 该版本需与 torchvision 兼容
    ```

6. 安装Fashionstar电机依赖：

    ```bash
    pip install lerobot_teleoperator_stararm102   #使用 pip 安装StarArm102_leader
    pip install lerobot_robot_stararm102    #使用 pip 安装StarArm102_follower
    ```

7. 检查 Pytorch 和 Torchvision

    由于通过 pip 安装 LeRobot 环境时会卸载原有的 Pytorch 和 Torchvision 并安装 CPU 版本，因此需要在 Python 中进行检查。

    ```python
    import torch
    print(torch.cuda.is_available())
    ```

    如果输出结果为 False，需要根据[官网教程](https://pytorch.org/index.html)重新安装 Pytorch 和 Torchvision。

### 接线

https://github.com/user-attachments/assets/56130bd9-21ee-4ae4-9cac-3817ac4d659f

### 手臂端口设置

在终端输入以下指令来找到两个机械臂对应的端口号：

```bash
lerobot-find-port
```

例如：

1. 识别Leader时端口的示例输出（例如，在 Mac 上为 `/dev/tty.usbmodem575E0031751`，或在 Linux 上可能为 `/dev/ttyUSB0`）
2. 识别Follower时端口的示例输出（例如，在 Mac 上为 `/dev/tty.usbmodem575E0032081`，或在 Linux 上可能为 `/dev/ttyUSB1`）

> [!NOTE]
>
> 如果识别不到ttyUSB0串口信息。尝试以下方法。
>
> 列出所有usb口。
>
> ```sh
> lsusb
> ```
>
> 
>
> 识别成功，查看ttyusb的信息
>
> ```sh
> sudo dmesg | grep ttyUSB
> ```
>
> 
>
> 最后一行显示断连，因为brltty在占用该USB设备号，移除掉就可以了
>
> ```sh
> sudo apt remove brltty
> ```
>
> 
>
> 最后，赋予权限
>
> ```sh
> sudo chmod 777 /dev/ttyUSB*
> ```
>

## 校准

如果是第一次校准，请对每个关节左右转动到极限位置。

如果是重新校准，按照命令提示输入字母c后按Enter键。

下面是参考值,通常情况下，真实的限位参考值的±10°范围内。

| 舵机ID  | 角度下限参考值 | 角度上限参考值 | 备注 |
| --- | ---: | ---: | --- |
| motor_0 | -180° | 180° | 转动到限位处 |
| motor_1 | -90° | 90° | 转动到限位处 |
| motor_2 | -90° | 90° | 转动到限位处 |
| motor_3 | -180° | 180° | 没有限位，需转动到角度上下限参考值 |
| motor_4 | -90° | 90° | 转动到限位处 |
| motor_5 | -180° | 180° | 没有限位，需转动到角度上下限参考值 |
| motor_6 | 0° | 100° | 转动到限位处 |

### leader

> [!TIP]
>
> 将leader连接到/dev/ttyUSB0，或者修改下面的命令。

```bash
lerobot-calibrate     --teleop.type=lerobot_teleoperator_stararm102 --teleop.port=/dev/ttyUSB0 --teleop.id=my_awesome_stararm102_leader_arm
```

### follower

> [!TIP]
>
> 将follower连接到/dev/ttyUSB1，或者修改下面的命令。

```bash
lerobot-calibrate     --robot.type=lerobot_robot_stararm102 --robot.port=/dev/ttyUSB1 --robot.id=my_awesome_stararm102_follower_arm
```

## 遥操作

https://github.com/user-attachments/assets/23b3aa00-9889-48d3-ae2c-00ad50595e0a

您已准备好遥操作您的机器人（不包括摄像头）！运行以下简单脚本：

```bash
lerobot-teleoperate \
    --robot.type=lerobot_robot_stararm102 \
    --robot.port=/dev/ttyUSB1 \
    --robot.id=my_awesome_stararm102_follower_arm \
    --teleop.type=lerobot_teleoperator_stararm102 \
    --teleop.port=/dev/ttyUSB0 \
    --teleop.id=my_awesome_stararm102_leader_arm
```

远程操作命令将自动检测下列参数:

1. 识别任何缺失的校准并启动校准程序。
2. 连接机器人和远程操作设备并开始远程操作。

程序启动后，悬停按钮依旧生效。

## 添加摄像头

https://github.com/user-attachments/assets/82650b56-96be-4151-9260-2ed6ab8b133f

在插入您的两个 USB 摄像头后，运行以下脚本以检查摄像头的端口号，切记摄像头避免插在USB Hub上，USB Hub速率太慢会导致读不到图像数据。

```bash
lerobot-find-cameras opencv # or realsense for Intel Realsense cameras
```

终端将打印出以下信息。以我的笔记本为例，笔记本摄像头为Camera0和Camera1，index_or_path分别为2和4。

```markdown
--- Detected Cameras ---
Camera #0:
  Name: OpenCV Camera @ /dev/video2
  Type: OpenCV
  Id: /dev/video2
  Backend api: V4L2
  Default stream profile:
    Format: 0.0
    Width: 640
    Height: 480
    Fps: 30.0
--------------------
Camera #1:
  Name: OpenCV Camera @ /dev/video4
  Type: OpenCV
  Id: /dev/video4
  Backend api: V4L2
  Default stream profile:
    Format: 0.0
    Width: 640
    Height: 360
    Fps: 30.0
--------------------

Finalizing image saving...
Image capture finished. Images saved to outputs/captured_images
```

确认外接摄像头后，将摄像头信息替换下方cameras信息您将能够在遥操作时在计算机上显示摄像头：

```bash
lerobot-teleoperate \
    --robot.type=lerobot_robot_stararm102 \
    --robot.port=/dev/ttyUSB1 \
    --robot.id=my_awesome_stararm102_follower_arm \
    --robot.cameras="{ front: {type: opencv, index_or_path: 2, width: 640, height: 480, fps: 30}}" \
    --teleop.type=lerobot_teleoperator_stararm102 \
    --teleop.port=/dev/ttyUSB0 \
    --teleop.id=my_awesome_stararm102_leader_arm \
    --display_data=true
# new
# lerobot-teleoperate \
#     --robot.type=lerobot_robot_stararm102 \
#     --robot.port=/dev/ttyUSB1 \
#     --robot.id=my_awesome_stararm102_follower_arm \
#     --robot.cameras="{ front: {type: opencv, index_or_path: 2, width: 640, height: 480, fps: 30, fourcc: "MJPG"}}" \
#     --teleop.type=lerobot_teleoperator_stararm102 \
#     --teleop.port=/dev/ttyUSB0 \
#     --teleop.id=my_awesome_stararm102_leader_arm \
#     --display_data=true
```

## 数据集制作采集

https://github.com/user-attachments/assets/8bb25714-783a-4f29-83dd-58b457aed80c

> [!TIP]
>
> 如果您想使用 Hugging Face Hub 的功能来上传您的数据集，请参考以下官方文章链接。本教程将不涉及这部分内容。
>
> [lmitation Learning for Robots](https://huggingface.co/docs/lerobot/il_robots?teleoperate_koch_camera=Command)
>
>

一旦您熟悉了遥操作，您就可以开始您的第一个数据集。

记录 10 个回合：

```bash
lerobot-record \
    --robot.type=lerobot_robot_stararm102 \
    --robot.port=/dev/ttyUSB1 \
    --robot.id=my_awesome_stararm102_follower_arm \
    --robot.cameras="{ up: {type: opencv, index_or_path: /dev/video2, width: 640, height: 480, fps: 30},front: {type: opencv, index_or_path: /dev/video4, width: 640, height: 480, fps: 30}}" \
    --teleop.type=lerobot_teleoperator_stararm102 \
    --teleop.port=/dev/ttyUSB0 \
    --teleop.id=my_awesome_stararm102_leader_arm \
    --display_data=true \
    --dataset.repo_id=starai/record-test \
    --dataset.episode_time_s=30 \
    --dataset.reset_time_s=30 \
    --dataset.num_episodes=10 \
    --dataset.push_to_hub=False \
    --dataset.single_task="Grab the black cube"
```

### 记录功能

- record提供了一套用于在机器人操作过程中捕获和管理数据的工具:

#### 1.数据存储

- 数据使用 `LeRobotDataset` 格式存储，并在录制过程中存储在磁盘上。

#### 2.检查点和恢复

- 记录期间会自动创建检查点。
- 如果出现问题，可以通过使用 重新运行相同的命令来恢复。恢复录制时，必须设置为**要录制的额外剧集数**，而不是数据集中的目标总剧集数！`--resume=true` `--dataset.num_episodes`
- 要从头开始录制，请**手动删除**数据集目录。

#### 3.记录参数

使用命令行参数设置数据记录流：

--dataset.episode_time_s=60每个数据记录插曲的持续时间(默认值:60秒)。
--dataset.reset_time_s=60每集后重置环境的持续时间(默认:60秒)。
--dataset.num_episodes=50记录的总集数(默认值:50秒)。

#### 4.录制期间的键盘控制

使用键盘快捷键控制数据记录流：

- 按**右方向键(→)** ： 提前停止当前情节或重置时间,然后移动到下一个。
- 按**左方向键(←)** ：取消当前插曲并重新录制。
- 按**ESC**：立即停止会话,编码视频并上传数据集。

>[!TIP]
>
>在 Linux 上,如果左右箭头键和转义键在数据记录过程中没有任何效果,请确保已设置$DISPLAY环境变量。参见 pynput 限制。
>
>一旦你熟悉了数据记录,你就可以创建一个更大的数据集进行训练。一个好的开始任务是抓住一个物体在不同的位置,并把它放在一个垃圾箱。我们建议录制至少50集,每个地点10集。保持相机固定,并在整个录音中保持一致的抓握行为。还要确保你操纵的对象在相机上可见。一个好的经验法则是,你应该能够只看相机图像自己完成任务。

## 重播一个回合

播放已经录制好的动作，可以借此测试机器人动作的重复性。

```bash
lerobot-replay \
    --robot.type=lerobot_robot_stararm102 \
    --robot.port=/dev/ttyUSB1 \
    --robot.id=my_awesome_stararm102_follower_arm \
    --dataset.repo_id=starai/record-test \
    --dataset.episode=1 # choose the episode you want to replay
```

## 训练

要训练一个控制您机器人策略，以下是一个示例命令：

```bash
lerobot-train \
  --dataset.repo_id=starai/record-test \
  --policy.type=act \
  --output_dir=outputs/train/act_stararm102_test \
  --job_name=act_stararm102_test \
  --policy.device=cuda \
  --wandb.enable=False \
  --policy.repo_id=starai/my_policy
```

1. 我们提供了数据集作为参数。`dataset.repo_id=starai/record-test`
2. 我们为 .这将从 [`configuration_act.py`](https://github.com/huggingface/lerobot/blob/main/src/lerobot/policies/act/configuration_act.py) 加载配置。重要的是，此策略将自动适应机器人的电机状态、电机动作和相机的数量已保存在您的数据集中。`policy.type=act` `laptop` `phone`
3. 我们提供了使用[权重和偏差](https://docs.wandb.ai/quickstart)来可视化训练图。这是可选的，但如果您使用它，请确保您已通过运行 登录。`wandb.enable=true` `wandb login`

要从某个检查点恢复训练。

```bash
lerobot-train \
  --config_path=outputs/train/act_stararm102_test/checkpoints/last/pretrained_model/train_config.json \
  --resume=true
```

## 运行推理并评估

运行以下命令记录 10 个评估回合：

```bash
lerobot-record  \
  --robot.type=lerobot_robot_stararm102 \
  --robot.port=/dev/ttyUSB1 \
  --robot.cameras="{ up: {type: opencv, index_or_path: /dev/video2, width: 640, height: 480, fps: 30},front: {type: opencv, index_or_path: /dev/video4, width: 640, height: 480, fps: 30}}" \
  --robot.id=my_awesome_stararm102_follower_arm \
  --display_data=false \
  --dataset.repo_id=starai/eval_record-test \
  --dataset.single_task="Put lego brick into the transparent box" \
  --policy.path=outputs/train/act_stararm102_test/checkpoints/last/pretrained_model
  # <- Teleop optional if you want to teleoperate in between episodes \
  # --teleop.type=lerobot_teleoperator_stararm102 \
  # --teleop.port=/dev/ttyUSB0 \
  # --teleop.id=my_awesome_stararm102_leader_arm \
```

## FAQ

- 如果使用本文档教程，请git clone本文档推荐的github仓库`https://github.com/servodevelop/lerobot.git`。

- 如果遥操作正常，而带Camera的遥操作无法显示图像界面，请参考[这里](https://github.com/huggingface/lerobot/pull/757/files)

- 如果在数据集遥操作过程中出现libtiff的问题，请更新libtiff版本。

  ```bash
  conda install libtiff==4.5.0  #for Ubuntu 22.04 is libtiff==4.5.1
  ```

- 执行完安装LeRobot可能会自动卸载gpu版本的pytorch，所以需要在手动安装torch-gpu。

- 对于Jetson，请先安装[Pytorch和Torchvsion](https://github.com/Seeed-Projects/reComputer-Jetson-for-Beginners/blob/main/3-Basic-Tools-and-Getting-Started/3.3-Pytorch-and-Tensorflow/README.md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)再执行`conda install -y -c conda-forge ffmpeg`,否则编译torchvision的时候会出现ffmpeg版本不匹配的问题。

- 在3060的8G笔记本上训练ACT的50组数据的时间大概为6小时，在4090和A100的电脑上训练50组数据时间大概为2~3小时。

- 数据采集过程中要确保摄像头位置和角度和环境光线的稳定，并且减少摄像头采集到过多的不稳定背景和行人，否则部署的环境变化过大会导致机械臂无法正常抓取。

- 数据采集命令的num-episodes要确保采集数据足够，不可中途手动暂停，因为在数据采集结束后才会计算数据的均值和方差，这在训练中是必要的数据。

- 如果程序提示无法读取USB摄像头图像数据，请确保USB摄像头不是接在Hub上的，USB摄像头必须直接接入设备，确保图像传输速率快。

## 参考文档

矽递科技英文Wiki文档：[How to use the SO10xArm robotic arm in Lerobot | Seeed Studio Wiki]([如何在 Lerobot 中使用 SO100/101Arm 机器人手臂 | Seeed Studio Wiki](https://wiki.seeedstudio.com/cn/lerobot_so100m/))

Huggingface Project:[Lerobot](https://github.com/huggingface/lerobot/tree/main)

Huggingface:[LeRobot](https://huggingface.co/docs/lerobot/index)

ACT or ALOHA:[Learning Fine-Grained Bimanual Manipulation with Low-Cost Hardware](https://tonyzhaozh.github.io/aloha/)

VQ-BeT:[VQ-BeT: Behavior Generation with Latent Actions](https://sjlee.cc/vq-bet/)

Diffusion Policy:[Diffusion Policy](https://diffusion-policy.cs.columbia.edu/)

TD-MPC:[TD-MPC](https://www.nicklashansen.com/td-mpc/)

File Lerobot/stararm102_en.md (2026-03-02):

# How to use the LeRobot-starai robotic arm in Lerobot

https://github.com/user-attachments/assets/dcbd27da-9e24-4562-b682-ff3212f6ac4a

## Products Introduction

1. **Open-Source & Developer-Friendly**
   It is an open-source, developer-friendly 6+1 DoF robotic arm solution from [Fishion Star Technology Limited](https://fashionrobo.com/).
2. **Integration with LeRobot**
   Designed for integration with [LeRobot Platform](https://github.com/huggingface/lerobot) , which provides PyTorch models, datasets, and tools for imitation learning in real-world robotic tasks — including data collection, simulation, training, and deployment.
3. **Comprehensive Learning Resources**
   Provides comprehensive open-source learning resources like assembly and calibration guides, and example custom grasping tasks to assist users in quickly getting started and developing robotic applications.
4. **Compatible with Nvidia**
   Supports deployment on the reComputer Mini J4012 Orin NX 16GB platform.

## Main Features

- Ready to Go — No Assembly Required. Just Unbox and Dive into the World of AI.
- 6+1 Degrees of Freedom and a 470mm Reach — Built for Versatility and Precision.
- Parallel Gripper with 66mm Maximum Opening — Modular Fingertips for Quick-Replace Flexibility.

## Initial Environment Setup

For Ubuntu X86:

- Ubuntu 22.04
- CUDA 12+
- Python 3.10
- Troch 2.6

## Installation

### Install LeRobot

1. Environments such as pytorch and torchvision need to be installed based on your CUDA.

    Install Miniconda: For Jetson:

    ```bash
    wget https://repo.anaconda.com/miniconda/Miniconda3-latest-Linux-aarch64.sh
    chmod +x Miniconda3-latest-Linux-aarch64.sh
    ./Miniconda3-latest-Linux-aarch64.sh
    source ~/.bashrc
    ```

    Or, For X86 Ubuntu 22.04:

    ```bash
    mkdir -p ~/miniconda3
    cd miniconda3
    wget https://repo.anaconda.com/miniconda/Miniconda3-latest-Linux-x86_64.sh -O ~/miniconda3/miniconda.sh
    bash ~/miniconda3/miniconda.sh -b -u -p ~/miniconda3
    rm ~/miniconda3/miniconda.sh
    source ~/miniconda3/bin/activate
    conda init --all
    ```

2. Create and activate a fresh conda environment for lerobot

    ```bash
    conda create -y -n lerobot python=3.10 && conda activate lerobot
    ```

3. When using miniconda, install ffmpeg in your environment:

    ```bash
    conda install ffmpeg -c conda-forge
    ```

    This usually installs ffmpeg 7.X for your platform compiled with the libsvtav1 encoder. If libsvtav1 is not supported (check supported encoders with ffmpeg -encoders), you can:

    - [On any platform] Explicitly install ffmpeg 7.X using:

    ```bash
    conda install ffmpeg=7.1.1 -c conda-forge
    ```

4. Install LeRobot:

    ```bash
    cd ~/lerobot && pip install -e .
    ```

    For Jetson Jetpack devices (please ensure that Pytorch-gpu and Torchvision have been installed following Step 5 of [this tutorial](https://github.com/Seeed-Projects/reComputer-Jetson-for-Beginners/tree/main/3-Basic-Tools-and-Getting-Started/3.5-Pytorch) before proceeding with this step):

    ```bash
    conda install -y -c conda-forge "opencv>=4.10.0.84"  # Install OpenCV and other dependencies via conda, only for Jetson Jetpack 6.0+
    conda remove opencv   # Uninstall OpenCV
    pip3 install opencv-python==4.10.0.84  # Install the specified version of OpenCV using pip3
    conda install -y -c conda-forge ffmpeg
    conda uninstall numpy
    pip3 install numpy==1.26.0  # This version needs to be compatible with torchvision
    ```

5. Install Fashionstar Motor Dependencies:

     ```bash
    pip install lerobot_teleoperator_stararm102    # Install StarArm102_leader via pip
    pip install lerobot_robot_stararm102    # Install StarArm102_follower via pip
    ```

6. Check Pytorch and Torchvision

    Since installing the lerobot environment via pip will uninstall the original Pytorch and Torchvision and install the CPU versions of Pytorch and Torchvision, you need to perform a check in Python.

    ```python
    import torch
    print(torch.cuda.is_available())
    ```

    If the result is False, you need to reinstall Pytorch and Torchvision according to the [official website tutorial](https://fashionrobo.com/).

### Unboxing

https://github.com/user-attachments/assets/56130bd9-21ee-4ae4-9cac-3817ac4d659f

UC-01 debuging board switch：

### Configure arm port

Run the following command in the terminal to find USB ports associated to your arms：

```bash
lerobot-find-port
```

For example：

1. Example output when identifying the leader arm's port (e.g., `/dev/tty.usbmodem575E0031751` on Mac, or possibly `/dev/ttyUSB0` on Linux):
2. Example output when identifying the follower arm's port (e.g., `/dev/tty.usbmodem575E0032081`on Mac, or possibly `/dev/ttyUSB1` on Linux):

> [!NOTE]
>
> If the ttyUSB0 serial port cannot be identified, try the following solutions:
>
> List all USB ports.
>
> ```sh
> lsusb
> ```
>
> 
>
> Once identified, check the information of the ttyusb.
>
> ```sh
> sudo dmesg | grep ttyUSB
> ```
>
> 
>
> The last line indicates a disconnection because brltty is occupying the USB. Removing brltty will resolve the issue.
>
> ```sh
> sudo apt remove brltty
> ```
>
> 
>
> Finally，use chmod command.
>
> ```sh
> sudo chmod 777 /dev/ttyUSB*
> ```
>

## Calibrate

### For Initial Calibration

Please rotate each joint left and right to the corresponding positions.

### For Re-Calibration

Follow the on-screen prompt: enter the letter "c" and press the Enter key.

Below are the reference values. Under normal circumstances, the actual limit reference values should fall within the range of **±10°** of these references.

| Servo ID | Lower Angle Limit | Upper Angle Limit | Notes |
| --- | ---: | ---: | --- |
| motor_0  | -180°  | 180° | Rotate to the limit position |
| motor_1  | -90°  | 90° | Rotate to the limit position |
| motor_2  | -90°  | 90° | Rotate to the limit position |
| motor_3  | -180°  | 180° | No limit; rotate to reference angle |
| motor_4  | -90°  | 90° | Rotate to the limit position |
| motor_5  | -180°  | 180° | No limit; rotate to reference angle |
| motor_6  | 0°  | 100° | Rotate to the limit position |

### leader

> [!TIP]
>
> Connect the leader to /dev/ttyUSB0, or modify the command below.

```bash
lerobot-calibrate     --teleop.type=lerobot_teleoperator_stararm102 --teleop.port=/dev/ttyUSB0 --teleop.id=my_awesome_stararm102_leader_arm
```

### follower

> [!TIP]
>
> Connect the follower to /dev/ttyUSB1, or modify the command below.

```bash
lerobot-calibrate     --robot.type=lerobot_robot_stararm102 --robot.port=/dev/ttyUSB1 --robot.id=my_awesome_stararm102_follower_arm
```

## Teleoperate

https://github.com/user-attachments/assets/23b3aa00-9889-48d3-ae2c-00ad50595e0a

Then you are ready to teleoperate your robot (It won't display the cameras)! Run this simple script :

```bash
lerobot-teleoperate \
    --robot.type=lerobot_robot_stararm102 \
    --robot.port=/dev/ttyUSB1 \
    --robot.id=my_awesome_stararm102_follower_arm \
    --teleop.type=lerobot_teleoperator_stararm102 \
    --teleop.port=/dev/ttyUSB0 \
    --teleop.id=my_awesome_stararm102_leader_arm
```

After the program starts, the Hover Lock Technology remains functional.

## Add cameras

https://github.com/user-attachments/assets/82650b56-96be-4151-9260-2ed6ab8b133f

After inserting your two USB cameras, run the following script to check the port numbers of the cameras. It is important to remember that the camera must not be connected to a USB Hub; instead, it should be plugged directly into the device. The slower speed of a USB Hub may result in the inability to read image data.

```bash
lerobot-find-cameras opencv # or realsense for Intel Realsense cameras
```

The terminal will print out the following information. For example, the laptop camera is `index 2`, and the USB camera is `index 4`.

```markdown
--- Detected Cameras ---
Camera #0:
  Name: OpenCV Camera @ /dev/video2
  Type: OpenCV
  Id: /dev/video2
  Backend api: V4L2
  Default stream profile:
    Format: 0.0
    Width: 640
    Height: 480
    Fps: 30.0
--------------------
Camera #1:
  Name: OpenCV Camera @ /dev/video4
  Type: OpenCV
  Id: /dev/video4
  Backend api: V4L2
  Default stream profile:
    Format: 0.0
    Width: 640
    Height: 360
    Fps: 30.0
--------------------

Finalizing image saving...
Image capture finished. Images saved to outputs/captured_images
```

After confirming that the external camera is connected, replace the camera information below with the actual camera details. This will allow you to display the camera feed on your computer during teleoperation:

```bash
lerobot-teleoperate \
    --robot.type=lerobot_robot_stararm102 \
    --robot.port=/dev/ttyUSB1 \
    --robot.id=my_awesome_stararm102_follower_arm \
    --robot.cameras="{ front: {type: opencv, index_or_path: 2, width: 640, height: 480, fps: 30}}" \
    --teleop.type=lerobot_teleoperator_stararm102 \
    --teleop.port=/dev/ttyUSB0 \
    --teleop.id=my_awesome_stararm102_leader_arm \
    --display_data=true
```

## Record the dataset

https://github.com/user-attachments/assets/8bb25714-783a-4f29-83dd-58b457aed80c

> [!TIP]
>
> Use the features of Hugging Face Hub to upload your dataset, and please refer to the following official article link.
>
> [lmitation Learning for Robots](https://huggingface.co/docs/lerobot/il_robots?teleoperate_koch_camera=Command)
>
>

Once you're familiar with teleoperation, you can record your first dataset.

Record 10 episodes.

```bash
lerobot-record \
    --robot.type=lerobot_robot_stararm102 \
    --robot.port=/dev/ttyUSB1 \
    --robot.id=my_awesome_stararm102_follower_arm \
    --robot.cameras="{ up: {type: opencv, index_or_path: /dev/video2, width: 640, height: 480, fps: 30},front: {type: opencv, index_or_path: /dev/video4, width: 640, height: 480, fps: 30}}" \
    --teleop.type=lerobot_teleoperator_stararm102 \
    --teleop.port=/dev/ttyUSB0 \
    --teleop.id=my_awesome_stararm102_leader_arm \
    --display_data=true \
    --dataset.repo_id=starai/record-test \
    --dataset.episode_time_s=30 \
    --dataset.reset_time_s=30 \
    --dataset.num_episodes=10 \
    --dataset.push_to_hub=False \
    --dataset.single_task="Grab the black cube"
```

## Replay an episode

```bash
lerobot-replay \
    --robot.type=lerobot_robot_stararm102 \
    --robot.port=/dev/ttyUSB1 \
    --robot.id=my_awesome_stararm102_follower_arm \
    --dataset.repo_id=starai/record-test \
    --dataset.episode=1 # choose the episode you want to replay
```

## Train

Train a policy to control your robot

```bash
lerobot-train \
  --dataset.repo_id=starai/record-test \
  --policy.type=act \
  --output_dir=outputs/train/act_stararm102_test \
  --job_name=act_stararm102_test \
  --policy.device=cuda \
  --wandb.enable=False \
  --policy.repo_id=starai/my_policy
```

To resume training from a checkpoint

```bash
lerobot-train \
  --config_path=outputs/train/act_viola_test/checkpoints/last/pretrained_model/train_config.json \
  --resume=true
```

## Evaluate your policy

Run the following command to record 10 evaluation episodes:

```bash
lerobot-record  \
  --robot.type=lerobot_robot_stararm102 \
  --robot.port=/dev/ttyUSB1 \
  --robot.cameras="{ up: {type: opencv, index_or_path: /dev/video2, width: 640, height: 480, fps: 30},front: {type: opencv, index_or_path: /dev/video4, width: 640, height: 480, fps: 30}}" \
  --robot.id=my_awesome_stararm102_follower_arm \
  --display_data=false \
  --dataset.repo_id=starai/eval_record-test \
  --dataset.single_task="Put lego brick into the transparent box" \
  --policy.path=outputs/train/act_stararm102_test/checkpoints/last/pretrained_model
  # <- Teleop optional if you want to teleoperate in between episodes \
  # --teleop.type=lerobot_teleoperator_stararm102 \
  # --teleop.port=/dev/ttyUSB0 \
  # --teleop.id=my_awesome_stararm102_leader_arm \
```

## Reference Documentation

Seeed Wiki：[How to use the SO10xArm robotic arm in Lerobot | Seeed Studio Wiki]([如何在 Lerobot 中使用 SO100/101Arm 机器人手臂 | Seeed Studio Wiki](https://wiki.seeedstudio.com/cn/lerobot_so100m/))

Huggingface Project:[Lerobot](https://github.com/huggingface/lerobot/tree/main)

Huggingface:[LeRobot](https://huggingface.co/docs/lerobot/index)

ACT or ALOHA:[Learning Fine-Grained Bimanual Manipulation with Low-Cost Hardware](https://tonyzhaozh.github.io/aloha/)

VQ-BeT:[VQ-BeT: Behavior Generation with Latent Actions](https://sjlee.cc/vq-bet/)

Diffusion Policy:[Diffusion Policy](https://diffusion-policy.cs.columbia.edu/)

TD-MPC:[TD-MPC](https://www.nicklashansen.com/td-mpc/)

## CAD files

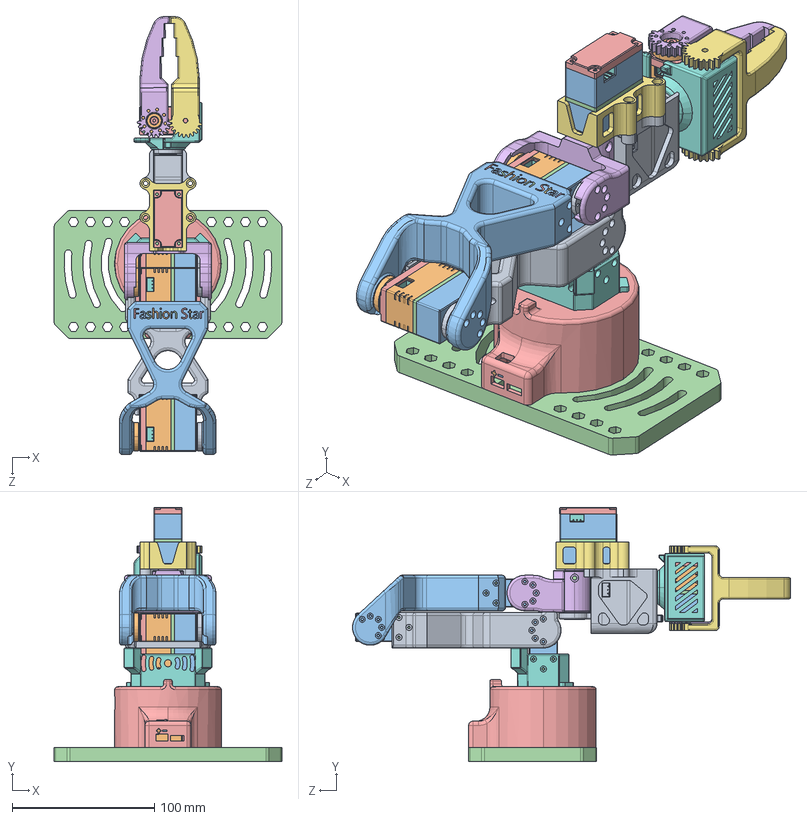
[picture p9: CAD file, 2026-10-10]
hardware/102-fl/step/assembly/star-arm-102-fl-assembly-export-2026-10-10.STEP
160.0 x 178.9 x 307.9 mm
RX8-U50H-M(2)
RX8-U50H-M
RA8-U35H-M x 2
RA8-U27H-M-C005
#3______1^star-arm-102-fl-export-2026-09-27(2)_star-arm-102-fl-export-2026-09-27.STEP
#4__________^star-arm-102-fl-export-2026-09-27(2)_star-arm-102-fl-export-2026-09-27.STEP
__link1________^star-arm-102-fl-export-2026-09-27(2)_star-arm-102-fl-export-2026-09-27.STEP
link2_rebot^star-arm-102-fl-export-2026-09-27(2)_star-arm-102-fl-export-2026-09-27.STEP
________-0^star-arm-102-fl-export-2026-09-27(2)_star-arm-102-fl-export-2026-09-27.STEP
star102_______^star-arm-102-fl-export-2026-09-27(2)_star-arm-102-fl-export-2026-09-27.STEP
star102_______^star-arm-102-fl-export-2026-09-27(2)_star-arm-102-fl-export-2026-09-27-0.STEP
star102_________^star-arm-102-fl-export-2026-09-27(2)_star-arm-102-fl-export-2026-09-27.STEP
star102_link6____^star-arm-102-fl-export-2026-09-27(2)_star-arm-102-fl-export-2026-09-27.STEP
link3_rebot_V2(3mm).step.STEP
RA8-U35H-M(3)
RA8-U35H-M-C047

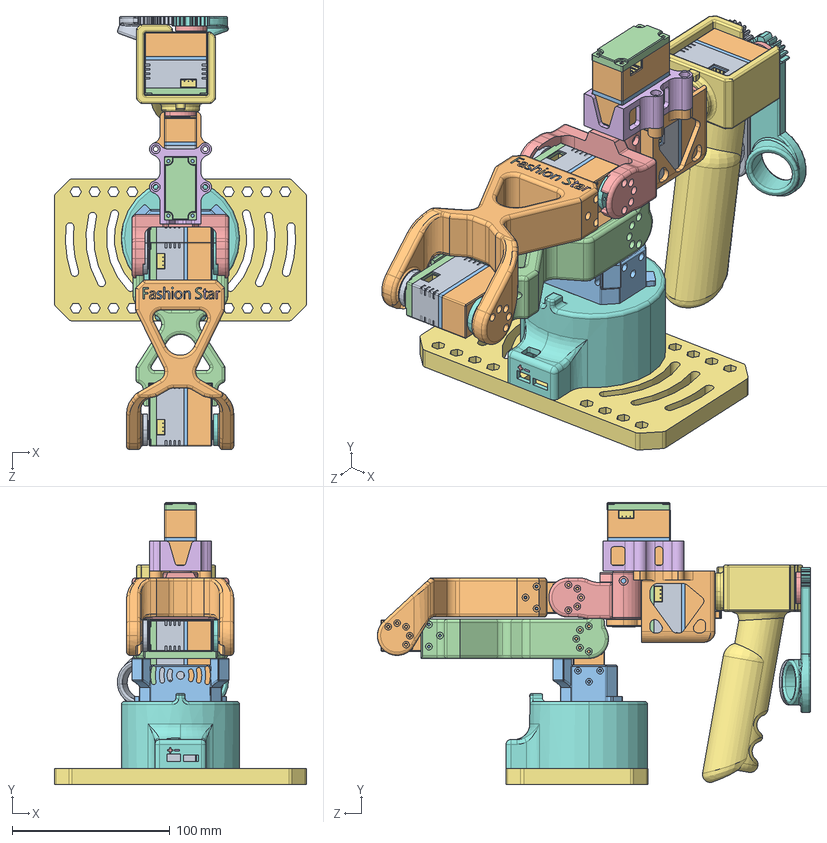
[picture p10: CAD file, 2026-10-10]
hardware/102-hd/step/assembly/star-arm-102-hd-assembly-export-2026-10-10.STEP
160.0 x 178.9 x 274.8 mm
RP8-U45H-M x 3
RP8-U45H-M-C029
#3______1^star-arm-102-ld-hd-assembly-export-2026-07-21 (1)_star-arm-102-ld-hd-assembly-export-2026-10-8 .STEP
#4__________^star-arm-102-ld-hd-assembly-export-2026-07-21 (1)_star-arm-102-ld-hd-assembly-export-2026-10-8 .STEP
____^star-arm-102-ld-hd-assembly-export-2026-07-21 (1)_star-arm-102-ld-hd-assembly-export-2026-10-8 .STEP
________^star-arm-102-ld-hd-assembly-export-2026-07-21 (1)_star-arm-102-ld-hd-assembly-export-2026-10-8 .STEP
________2^star-arm-102-ld-hd-assembly-export-2026-07-21 (1)_star-arm-102-ld-hd-assembly-export-2026-10-8 .STEP
#5__________ ^star-arm-102-ld-hd-assembly-export-2026-07-21 (1)_star-arm-102-ld-hd-assembly-export-2026-10-8 .STEP
__link1________^star-arm-102-ld-hd-assembly-export-2026-07-21 (1)_star-arm-102-ld-hd-assembly-export-2026-10-8 .STEP
link2_rebot^star-arm-102-ld-hd-assembly-export-2026-07-21 (1)_star-arm-102-ld-hd-assembly-export-2026-10-8 .STEP
________-0^star-arm-102-ld-hd-assembly-export-2026-07-21 (1)_star-arm-102-ld-hd-assembly-export-2026-10-8 .STEP
link3_rebot_V2(3mm).step.STEP(2)
RP8-U45H-M(4)
RP8-U45H-M-C028 x 2

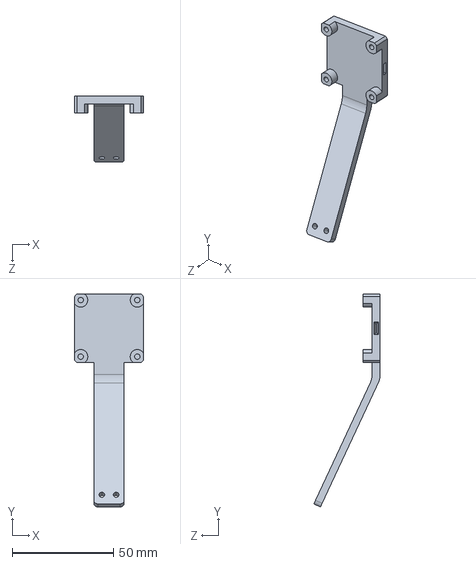
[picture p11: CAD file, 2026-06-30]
Hardware/parts/First-Person_Camera_Mount_Base.STEP
34.0 x 105.4 x 32.9 mm

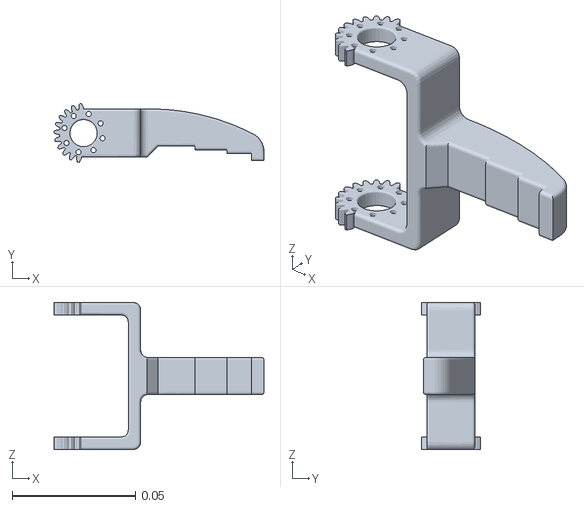
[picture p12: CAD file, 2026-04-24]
ROS2_HUMBLE/src/stararm102_description/meshes/link7_right.STL
0.0851 x 0.0238 x 0.0596

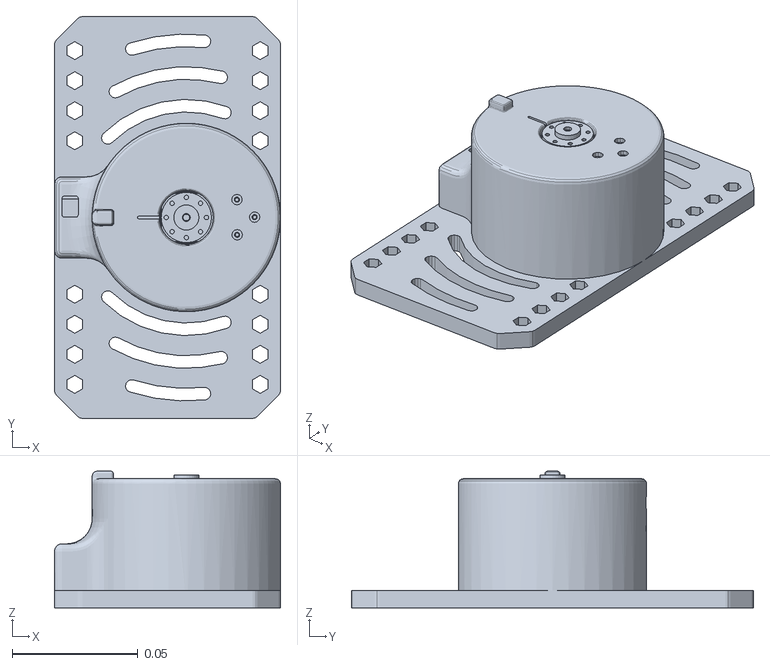
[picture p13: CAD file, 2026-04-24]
ROS2_HUMBLE/src/stararm102_gazebo/meshes/base_link.STL
0.09 x 0.16 x 0.0544

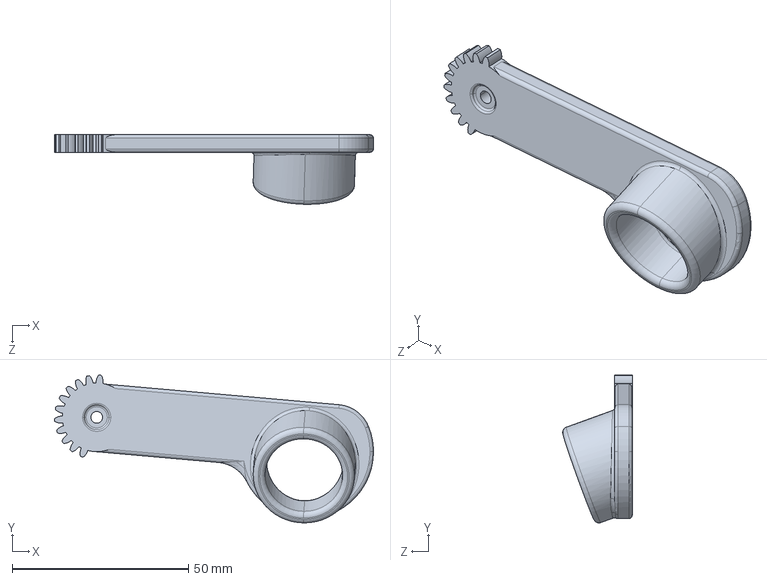
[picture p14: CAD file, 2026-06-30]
Hardware/parts/StarArm102_Finger_Ring_Right.STEP
90.6 x 42.0 x 19.8 mm

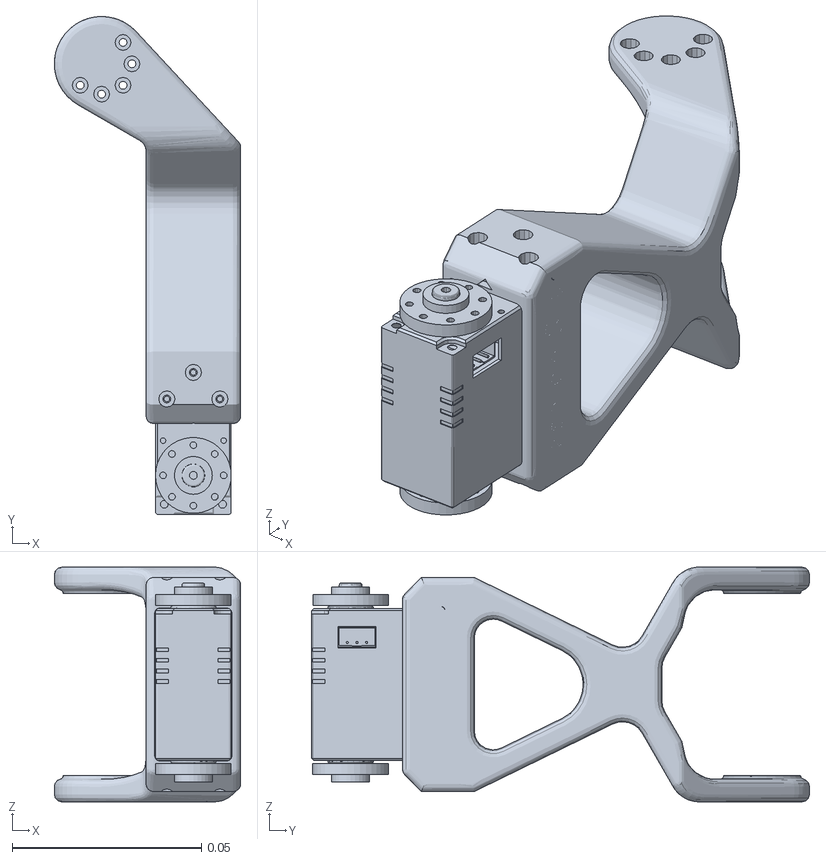
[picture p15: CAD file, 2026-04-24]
ROS2_HUMBLE/src/stararm102_description/meshes/link3.STL
0.0492 x 0.131 x 0.062

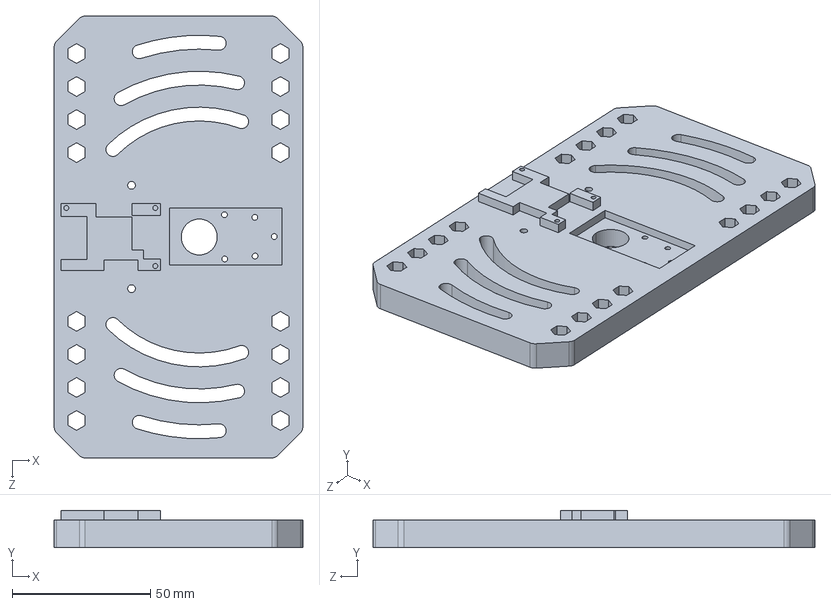
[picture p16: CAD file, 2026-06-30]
Hardware/parts/StarArm102_Base_Bottom.STEP
90.0 x 13.4 x 160.0 mm

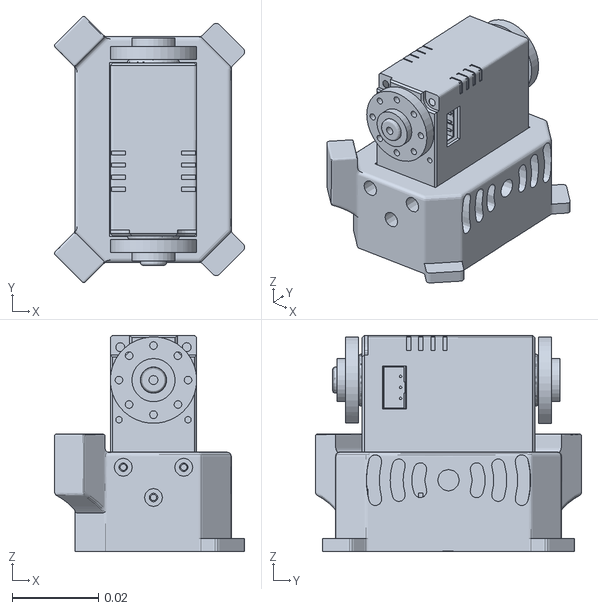
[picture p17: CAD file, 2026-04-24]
ROS2_HUMBLE/src/stararm102_description/meshes/link1.STL
0.044 x 0.0617 x 0.05

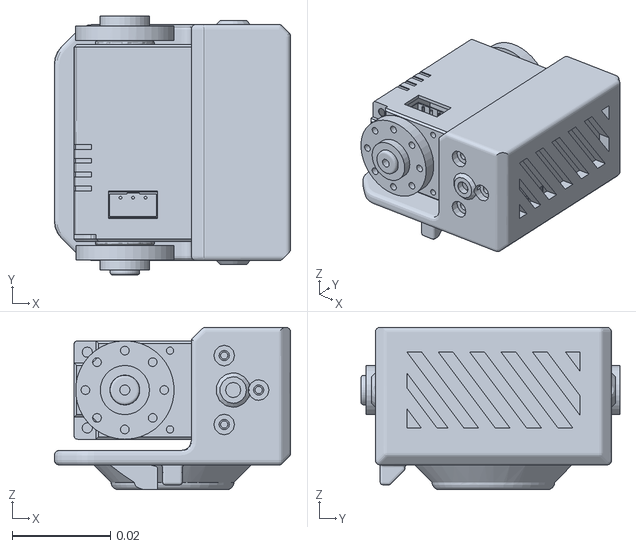
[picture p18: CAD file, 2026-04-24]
ROS2_HUMBLE/src/stararm102_gazebo/meshes/link6.STL
0.048 x 0.0526 x 0.033

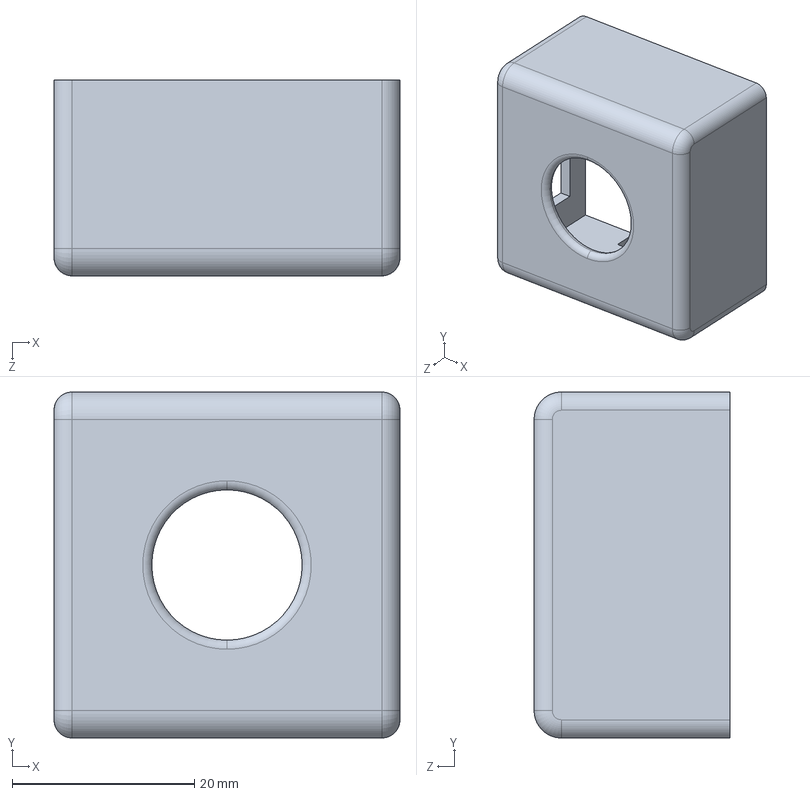
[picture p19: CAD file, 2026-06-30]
Hardware/parts/First-Person_Camera_Mount_Top_Cover.STEP
38.0 x 38.0 x 21.5 mm

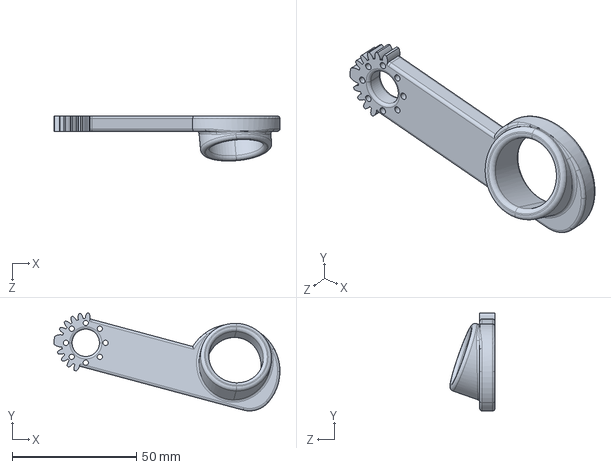
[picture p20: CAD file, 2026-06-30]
Hardware/parts/StarArm102_Finger_Ring_Left.STEP
91.1 x 39.4 x 18.2 mm

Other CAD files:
hardware/102-ld/step/assembly/star-arm-102-ld-assembly-export-2026-10-10.STEP
Hardware/cad/Star Arm102-LD.DWG
Hardware/parts/StarArm102_Base_Support.STEP
Hardware/parts/StarArm102_Base_Top.STEP
Hardware/parts/StarArm102_Handle.STEP
Hardware/parts/camera.STEP
ROS2_HUMBLE/src/stararm102_description/meshes/link2.STL
ROS2_HUMBLE/src/stararm102_description/meshes/link4.STL
ROS2_HUMBLE/src/stararm102_description/meshes/link5.STL
ROS2_HUMBLE/src/stararm102_description/meshes/link7_left.STL
ROS2_HUMBLE/src/stararm102_gazebo/meshes/link2.STL
ROS2_HUMBLE/src/stararm102_gazebo/meshes/link4.STL
ROS2_HUMBLE/src/stararm102_gazebo/meshes/link5.STL
ROS2_HUMBLE/src/stararm102_gazebo/meshes/link7_left.STL

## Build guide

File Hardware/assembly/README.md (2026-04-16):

### ✨ 装配教程正在产出中，敬请期待。
The assembly guide is currently in progress. Stay tuned.

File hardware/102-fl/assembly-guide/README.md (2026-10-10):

# Star Arm 102-FL Assembly Guide

[← 102-FL Hardware Resources](../README.md)　|　<sub>**English** / [简体中文](README.zh.md)</sub>

**On this page:**

- [🦾 Arm Assembly](#arm-assembly)
- [🤏 Flexible Gripper Assembly](#flexible-gripper-assembly)
- [📷 Camera Module Assembly](#camera-module-assembly)

## 🦾 Arm Assembly

Click the preview below to watch the 102-FL assembly video on YouTube.

Star Arm 102-FL assembly video (https://www.youtube.com/watch?v=9-ufaI8dwys)

## 🤏 Flexible Gripper Assembly

Click the preview below to watch the Star Arm 102 flexible gripper replacement and assembly guide on YouTube.

Star Arm 102 flexible gripper assembly video (https://www.youtube.com/watch?v=lqLOFoPuTgw)

**[▶ Watch the Flexible Gripper Assembly Guide →](https://www.youtube.com/watch?v=lqLOFoPuTgw)**

[→ Flexible Gripper Parts & BOM](../../flexible-gripper/README.md)

## 📷 Camera Module Assembly

Video coming soon.

[→ Camera Module Parts & BOM](../../camera-module/README.md)

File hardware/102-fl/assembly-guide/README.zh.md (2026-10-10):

# Star Arm 102-FL 装配指南

[← 102-FL 硬件资源](../README.zh.md)　|　<sub>[English](README.md) / **简体中文**</sub>

**本页导航：**

- [🦾 手臂装配](#arm-assembly)
- [🤏 柔性夹爪装配](#flexible-gripper-assembly)
- [📷 摄像头模组装配](#camera-module-assembly)

## 🦾 手臂装配

点击下方封面，在 YouTube 观看 102-FL 装配视频。

Star Arm 102-FL 装配视频 (https://www.youtube.com/watch?v=9-ufaI8dwys)

## 🤏 柔性夹爪装配

点击下方封面，在 YouTube 观看 Star Arm 102 柔性夹爪更换与装配指南。

Star Arm 102 柔性夹爪装配视频 (https://www.youtube.com/watch?v=lqLOFoPuTgw)

**[▶ 观看柔性夹爪装配指南 →](https://www.youtube.com/watch?v=lqLOFoPuTgw)**

[→ 柔性夹爪零件与 BOM](../../flexible-gripper/README.zh.md)

## 📷 摄像头模组装配

装配视频待上线。

[→ 摄像头模组零件与 BOM](../../camera-module/README.zh.md)

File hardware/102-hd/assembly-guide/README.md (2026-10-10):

# Star Arm 102-HD Assembly Guide

[← 102-HD Hardware Resources](../README.md)　|　<sub>**English** / [简体中文](README.zh.md)</sub>

**On this page:**

- [🦾 Arm Assembly](#arm-assembly)
- [🔘 Button Installation & Wiring](#button-installation-wiring)

## 🦾 Arm Assembly

Use Fashion Star’s 102-LD main arm assembly video to assemble your Star Arm 102-HD. Click the preview below to watch on YouTube.

> **For 102-HD: replace the servos shown in the LD video with the corresponding purple coreless bus servos supplied for HD. The remaining main arm assembly steps are the same as for 102-LD.**

Star Arm 102-LD main arm assembly video — reference for 102-HD with the servo substitution above (https://www.youtube.com/watch?v=flTCgBx3K0M)

## 🔘 Button Installation & Wiring

Use the photo below as a reference for the button module’s position on the base, connector orientation, and cable routing. Click the photo to view the full-size image.

<a href="images/star-arm-102-hd-button-wiring.jpg">102-HD button module mounting position and wiring reference</a>

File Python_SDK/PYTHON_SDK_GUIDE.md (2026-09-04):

# Python SDK - StarArm 102 机械臂控制





---

## 📖 简介

Python SDK 是 StarArm 102 机械臂的 Python 控制接口，提供简单易用的 Python API 用于机械臂的实时控制。该 SDK 支持主从遥操作模式，可通过 UART 串口直接控制机械臂舵机。

### ✨ 核心特性

- 🤖 **主从遥操作**：支持 Leader 机械臂实时控制 Follower 机械臂
- ⚡ **高实时性**：支持 100Hz+ 的控制频率
- 🎯 **多关节控制**：同时控制 7 个舵机关节
- 🔒 **HD 锁定状态扩展**：Star Arm 102-HD 可通过锁定功能按键板提供锁定 / 解锁状态
- 📊 **性能监控**：实时显示控制频率
- 🔧 **简单易用**：基于 Python，无需复杂配置

---

## 🚀 快速开始

### 环境要求

| 项目 | 要求 |
|---|---|
| 操作系统 | Ubuntu 22.04 |
| Python 版本 | Python 3.8+ |
| 硬件设备 | StarArm 102 机械臂 (Leader + Follower) |
| 串口设备 | 2个 USB 转串口设备 |

### 安装依赖

```bash
# 安装 Python 依赖包
pip install pyserial fashionstar-uart-sdk
```

### 硬件连接

1. **连接 Leader 机械臂**：
   - 使用 USB 线将 Leader 机械臂连接到计算机
   - 确认端口号（默认为 `/dev/ttyUSB0`）

2. **连接 Follower 机械臂**：
   - 使用 USB 线将 Follower 机械臂连接到计算机
   - 确认端口号（默认为 `/dev/ttyUSB1`）

3. **检查 USB 设备**：

```bash
# 查看所有串口设备
ls -l /dev/ttyUSB*

# 如果没有权限，赋予读写权限
sudo chmod 777 /dev/ttyUSB*
```

---

## 📂 项目结构

```bash
Python_SDK/
├── stararm102_ro.py       # 主从控制程序
└── PYTHON_SDK_GUIDE.md    # 本文档
```

---

## 💻 使用说明

### 基本使用

#### 1. 配置串口参数

编辑 `stararm102_ro.py` 文件，修改以下参数：

```python
SERVO_BAUDRATE = 1000000          # 舵机通信波特率
LEADER_PORT_NAME = "/dev/ttyUSB0" # Leader 机械臂端口号
FOLLOWER_PORT_NAME_Arr = ["/dev/ttyUSB1"]  # follower端口号
```

#### 2. 运行主从控制程序

```bash
# 赋予 USB 设备权限
sudo chmod 777 /dev/ttyUSB*

# 运行控制程序
python3 stararm102_ro.py
```

#### 3. 程序功能

程序启动后，将执行以下操作：

1. **初始化串口连接**：
   - 建立 Leader 机械臂的 UART 连接
   - 建立 Follower 机械臂的 UART 连接

2. **读取 Leader 状态**：
   - 实时读取 Leader 机械臂各关节角度
   - 支持 7 个舵机（ID: 0-6）

3. **控制 Follower 运动**：
   - 将 Leader 关节角度转换为 Follower 控制指令
   - 通过多圈角度间隔控制方式发送指令

4. **性能监控**：
   - 每秒显示当前运行频率（Hz）
   - 控制频率通常在 200Hz 左右

#### 4. 停止程序

按 `Ctrl+C` 终止程序运行

---

## 🔧 API 说明

### 主要函数

#### `main(args=None)`

主控制函数

**功能**：

- 初始化 Leader 和 Follower 串口连接
- 实时读取 Leader 关节角度
- 控制 Follower 跟随 Leader 运动
- 显示运行频率

**参数**：无

### 舵机控制参数

| 参数 | 值 | 说明 |
|---|-----|---|
| `SERVO_BAUDRATE` | 1000000 | 舵机通信波特率 |
| `LEADER_PORT_NAME` | /dev/ttyUSB0 | Leader 端口号 |
| `FOLLOWER_PORT_NAME` | /dev/ttyUSB1 | Follower 端口号 |
| `servo_ids` | [0,1,2,3,4,5,6] | 舵机 ID 列表 |

### Star Arm 102-HD 锁定功能按键板

Star Arm 102-HD 相比 LD 型号增加了一键锁定功能。按下锁定按键后，主臂会在当前姿态锁定，并让从臂同步进入锁定状态；再次按下按键后解除锁定。

#### 通过修改 `stararm102_ro.py` 开启按键功能

`stararm102_ro.py` 默认按照 Star Arm 102-LD 使用，不启用按键板。如果你使用的是 Star Arm 102-HD，需要编辑 `Python_SDK/stararm102_ro.py`，在 `main(args)` 函数开头找到默认配置：

```python
# 默认（102LD）
button_enable = False
button_id = 7
filtered_size = 30
```

将 `button_enable` 改为 `True`：

```python
# Star Arm 102-HD
button_enable = True
button_id = 7
filtered_size = 30
```

保存后正常运行：

```bash
python3 stararm102_ro.py
```

按键板默认 ID 为 `7`。如果你的按键板 ID 不是 `7`，请同步修改 `button_id` 的值。

也可以不改源码，直接通过启动参数开启 HD 配置：

```bash
python3 stararm102_ro.py --leader_type 102HD
```

---

## 📊 控制流程

```bash
┌─────────────┐
│  Leader     │
│  机械臂      │
└──────┬──────┘
       │ 读取角度
       ▼
┌──────────────────┐
│   UART 串口通信   │
│ (/dev/ttyUSB0)   │
└──────┬───────────┘
       │
       ▼
┌──────────────────┐
│  Python 控制程序  │
│  - 数据处理       │
│  - 角度转换       │
└──────┬───────────┘
       │ 发送指令
       ▼
┌──────────────────┐
│   UART 串口通信   │
│ (/dev/ttyUSB1)   │
└──────┬───────────┘
       │
       ▼
┌─────────────┐
│  Follower   │
│  机械臂      │
└─────────────┘
```

---

## 🛡️ 安全注意事项

1. **操作前检查**：
   - 确保 USB 连接稳定
   - 确认机械臂周围无障碍物
   - 检查电源供电是否正常

2. **急停控制**：
   - 按 `Ctrl+C` 立即停止程序
   - 如遇异常，拔掉 USB 线断开连接

3. **关节限制**：
   - 确保 Leader 机械臂在安全角度范围内操作
   - 避免快速大幅度移动

4. **电源管理**：
   - 使用稳定的 12V 电源
   - 避免电压波动

---

## 🐛 故障排除

### 常见问题

**Q1: 找不到 `/dev/ttyUSB0` 设备？**

```bash
# 检查 USB 设备
ls -l /dev/ttyUSB*

# 检查 USB 设备信息
lsusb

# 查看串口日志
sudo dmesg | grep ttyUSB

# 如果被 brltty 占用，卸载它
sudo apt remove brltty

# 赋予权限
sudo chmod 777 /dev/ttyUSB*
```

**Q2: 串口连接失败？**

- 检查 USB 线是否松动
- 确认端口号是否正确
- 尝试更换 USB 端口
- 检查驱动是否正常安装

**Q3: 控制频率过低？**

- 检查串口通信是否正常
- 减少其他程序运行负载
- 使用 USB 3.0 端口以提高速度

**Q4: Follower 机械臂不跟随 Leader？**

- 检查 Follower 端口号配置
- 确认舵机 ID 设置正确
- 检查串口通信波特率

---

## 📖 详细文档

- [主项目 README](../README_zh.md) - 项目总览
- [ROS2 HUMBLE 使用文档](../ROS2_HUMBLE/README.md) - ROS2 控制方式
- [Lerobot 使用文档](../Lerobot/README.md) - Lerobot 框架集成

---

## 🔗 相关链接

- [FashionStar UART SDK](https://github.com/servodevelop/servo-uart-rs485-sdk/)
- [华馨京科技官网](https://fashionrobo.com/)

---

## 📄 许可证

本项目基于 [MIT License](../LICENSE) 开源。

---

## 👥 致谢

- **感谢**：华馨京科技提供硬件支持和 SDK

---

**祝您使用愉快！如有问题，欢迎提交 Issue。**

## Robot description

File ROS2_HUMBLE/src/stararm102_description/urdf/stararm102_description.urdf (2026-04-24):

<?xml version="1.0" encoding="utf-8"?>
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
<robot name="stararm102_description">
      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
  <link name="world"/>

  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
  <joint name="world_to_base" type="fixed">
    <parent link="world"/>
    <child link="base_link"/>
    <origin xyz="0 0 0" rpy="0 0 0"/>
  </joint>
  <link name="base_link">
    <inertial>
      <origin xyz="-0.00507886641574018 -3.42055196168034E-05 0.0170541570471663" rpy="0 0 0" />
      <mass value="0.155441639095221" />
      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
    </inertial>
    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
  </link>
  <link name="link1">
    <inertial>
      <origin xyz="-0.000860795817551681 3.48041004087085E-05 0.0388877617080775" rpy="0 0 0" />
      <mass value="0.0365919096309897" />
      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
    </inertial>
    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
  </link>
  <joint name="joint1" type="revolute">
    <origin xyz="0 0 0.0283500000000012" rpy="0 0 0" />
    <parent link="base_link" />
    <child link="link1" />
    <axis xyz="0 0 -1" />
    <limit lower="-2.27" upper="2.27" effort="100" velocity="1" />
  </joint>
  <link name="link2">
    <inertial>
      <origin xyz="0.065445114144764 4.80766137382835E-05 1.86081119329107E-05" rpy="0 0 0" />
      <mass value="0.0677741447743621" />
      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
    </inertial>
    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
  </link>
  <joint name="joint2" type="revolute">
    <origin xyz="0.000100000000001007 0 0.0620250000000017" rpy="-1.5707963267949 0 3.14159265358979" />
    <parent link="link1" />
    <child link="link2" />
    <axis xyz="0 0 -1" />
    <limit lower="0" upper="3.14" effort="100" velocity="1" />
  </joint>
  <link name="link3">
    <inertial>
      <origin xyz="0.0139670047463857 -0.0548362979855048 -0.0260232297832349" rpy="0 0 0" />
      <mass value="0.062483417986533" />
      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
    </inertial>
    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
  </link>
  <joint name="joint3" type="revolute">
    <origin xyz="0.120565306190578 -0.0100999999999999 0.0259999999999978" rpy="0 0 -1.5707963267949" />
    <parent link="link2" />
    <child link="link3" />
    <axis xyz="0 0 -1" />
   <limit lower="-3.14" upper="0" effort="100" velocity="1" />
  </joint>
  <link name="link4">
    <inertial>
      <origin xyz="0.0233852853653051 -0.00064950134956597 -4.72632631462466E-06" rpy="0 0 0" />
      <mass value="0.0290020616470162" />
       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
    </inertial>
    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
  </link>
  <joint name="joint4" type="revolute">
    <origin xyz="0.0162194771204603 -0.107604056191361 -0.0259999999999976" rpy="0 0 -1.5707963267949" />
    <parent link="link3" />
    <child link="link4" />
    <axis xyz="0 0 -1" />
    <limit lower="-1.57" upper="2.2" effort="100" velocity="1" />
  </joint>
  <link name="link5">
    <inertial>
      <origin xyz="0.0239721333681056 1.60405714164091E-06 0.0123439857182104" rpy="0 0 0" />
      <mass value="0.04381347428302" />
      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
    </inertial>
    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
  </link>
  <joint name="joint5" type="revolute">
    <origin xyz="0.0350000000000005 -0.0013799999999997 0" rpy="-1.57079632679489 0 0" />
    <parent link="link4" />
    <child link="link5" />
    <axis xyz="0 0 -1" />
    <limit lower="-1.2" upper="1.2" effort="100" velocity="1" />
  </joint>
  <link name="link6">
    <inertial>
      <origin xyz="0.00415459393144704 6.90476927523165E-05 -0.0776167187492962" rpy="0 0 0" />
      <mass value="0.0277279215984807" />
      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
    </inertial>
    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
  </link>
  <joint name="joint6" type="revolute">
    <origin xyz="0.15168 0 0.005225" rpy="-1.5708 0 -1.5708" />
    <parent link="link5" />
    <child link="link6" />
    <axis xyz="0 0 -1" />
    <limit lower="-3.14" upper="3.14" effort="100" velocity="1" />
  </joint>
  <link name="link7_left">
    <inertial>
      <origin xyz="0.0281158042585857 0.00012184612342972 0.000226777556244492" rpy="0 0 0" />
      <mass value="0.0209012827567763" />
      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
    </inertial>
    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
  </link>
  <joint name="joint7_left" type="revolute">
    <origin xyz="0.012325 0 -0.07313" rpy="1.5708 -1.5708 0" />
    <parent link="link6" />
    <child link="link7_left" />
    <axis xyz="0 0 -1" />
    <limit lower="0" upper="1.57" effort="5" velocity="3.14" />
  </joint>
  <link name="link7_right">
    <inertial>
      <origin xyz="0.029631 -9.0637E-05 -0.0004" rpy="0 0 0" />
      <mass value="0.019895" />
      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
    </inertial>
    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
  </link>
  <joint name="joint7_right" type="revolute">
   <origin xyz="-0.009675 0 -0.07313" rpy="1.5708 -1.5708 0" />
    <parent link="link6" />
    <child link="link7_right" />
    <axis xyz="0 0 -1" />
    <limit lower="-1.57" upper="0" effort="5" velocity="3.14" />
    <mimic joint="joint7_left" multiplier="-1" />
  </joint>
</robot>

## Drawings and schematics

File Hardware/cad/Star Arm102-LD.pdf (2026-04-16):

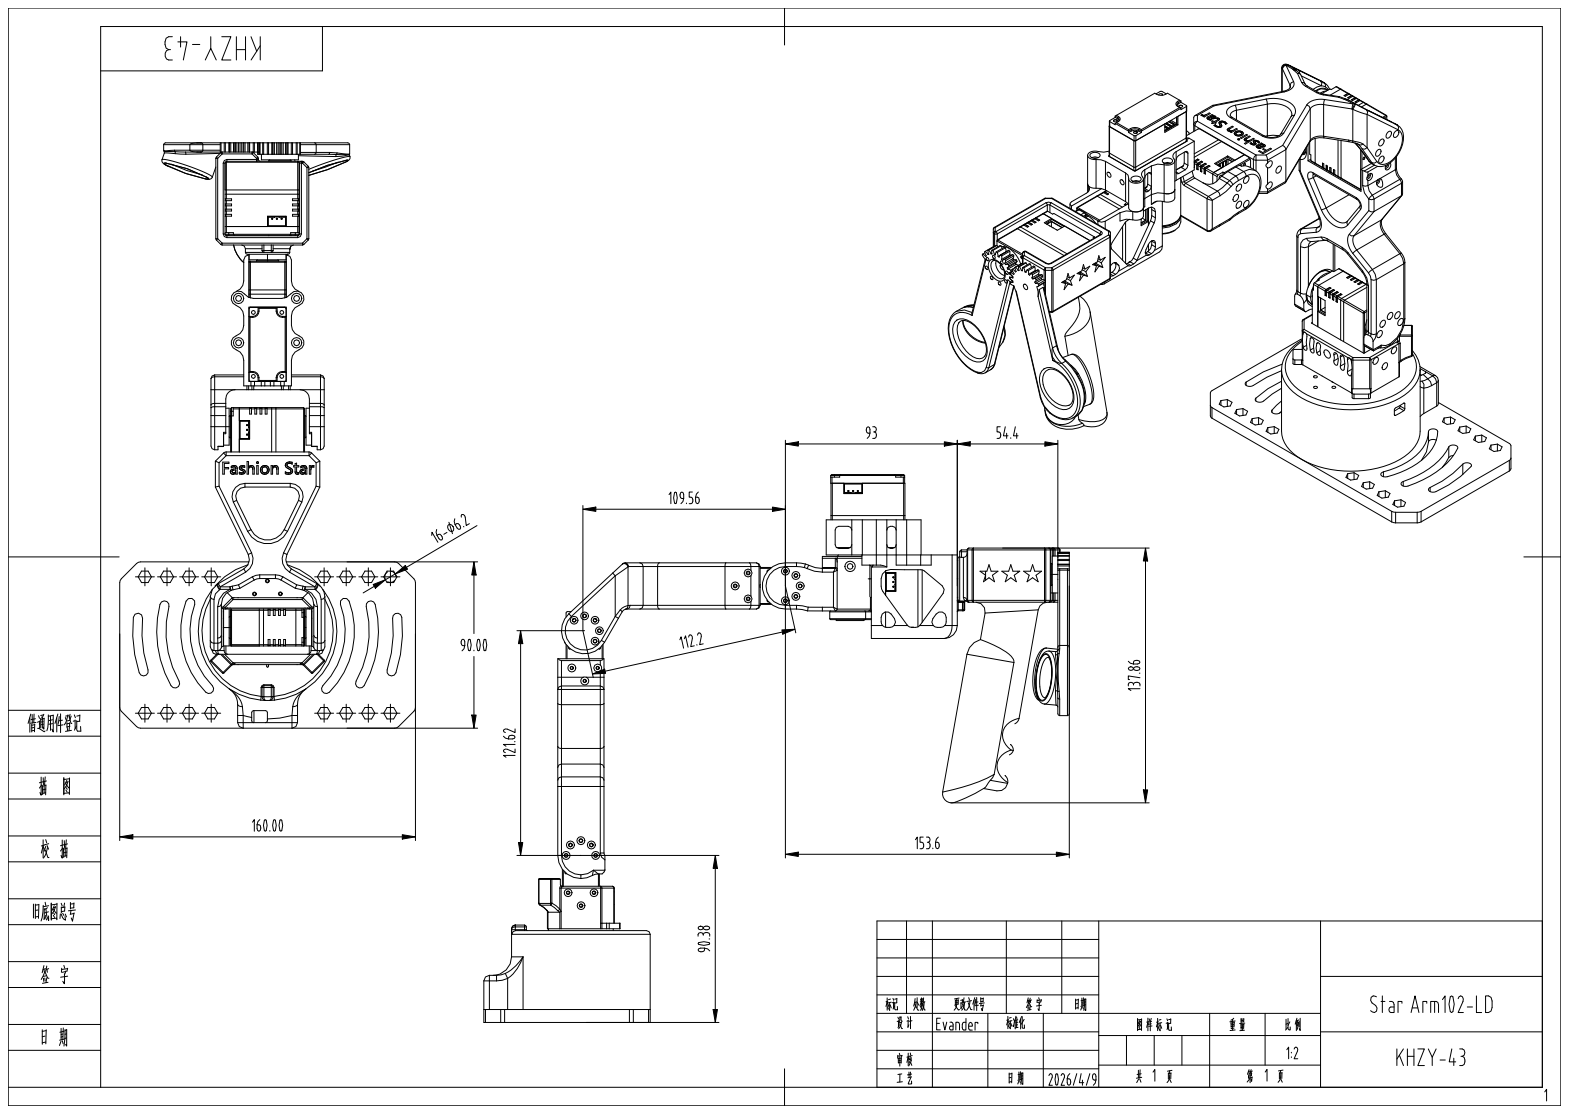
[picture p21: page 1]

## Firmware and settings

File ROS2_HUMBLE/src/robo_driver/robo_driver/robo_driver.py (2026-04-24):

#!/usr/bin/env python
# coding:utf-8
"""
机械臂驱动节点
Robot arm driver node
"""
import rclpy
from rclpy.node import Node
from robo_interfaces.srv import ReadData, WriteData
from robo_interfaces.msg import SetAngle
import struct
from sensor_msgs.msg import JointState
import math
import fashionstar_uart_sdk as uservo
import time
import serial
import traceback

ROBO_DRIVER_NODE = "robo_driver_node"  # 驱动节点名称 / driver node name
ROBO_SET_ANGLE_SUBSCRIBER = "set_angle_topic"  # 设置角度话题 / topic for setting angles

# PORT_NAME: 设置舵机串口号，默认使用/dev/ttyUSB0，当需要在同一个设备上使用多个机械臂时，需要修改该参数
# Port name: Serial port for servos, default "/dev/ttyUSB0", change when using multiple arms
# Whether to check servo angle on power-up, default True to ensure consistent init
SERVO_PORT_NAME = "/dev/ttyUSB0"  # 舵机串口号 <<< 修改为实际串口号
                                # Servo serial port <<< modify to actual port name
SERVO_BAUDRATE = 1000000  # 舵机的波特率 / Servo communication baud rate
servo_ids = list()

"""
舵机转手臂控制通用类
Universal class for servo-to-arm control
"""

class uservo_ex:
    JOINT_ = [
        "joint1",
        "joint2",
        "joint3",
        "joint4",
        "joint5",
        "joint6",
        "joint7_left",
    ]
    ROBO_TYPE_INDEX_JOINT = {
        value: index for index, value in enumerate(JOINT_)
    }
    SRV_NUM =7


    # 参数 / Parameters:
    def __init__(self,robo_type,log = None):
        self.ROBO_TYPE = robo_type
        self.INDEX_JOINT_ = {value: index for index, value in enumerate(self.JOINT_)}
        self.log = log
        # 初始化串口 / Initialize serial port
        try:
            self.uart = serial.Serial(port=SERVO_PORT_NAME,baudrate=SERVO_BAUDRATE,parity=serial.PARITY_NONE,stopbits=1,bytesize=8,timeout=0)
        except serial.SerialException as e:
            if self.log != None:
                self.log.error(f"{e}")
            raise ValueError(f"串口初始化失败: {e}")  # Serial port init failed
        try:
            self.uservo = uservo.UartServoManager(self.uart)
        except Exception as e:
            raise

        self.servo_ids = [0,1,2,3,4,5,6]
        self.ZERO_ANGLE = [0 for _ in range(self.SRV_NUM)]
        self.ZERO_ANGLE[6] = 500
        self.reset_multi_turn_angle(0xff)
        time.sleep(0.1)

    # 将角度转为弧度 / Convert degrees to radians
    @classmethod
    def degrees_to_radians(cls, degrees):
        radians = degrees * (math.pi / 180)
        return radians

    # 将角度转为米 / Convert degrees back to meters
    @classmethod
    def degrees_to_meters(cls, degrees):
        meters = (degrees / 100) * 0.032
        return meters

    # 将舵机角度转换为关节位置 / Servo angle to joint state mapping
    @classmethod
    def servoangle2jointstate(cls, servo_id, servo_angle):
        if servo_id in range(6):
            return cls.degrees_to_radians(servo_angle)
        elif servo_id == 6:
            # Joint7 axis was flipped in URDF, so invert the gripper feedback too.
            return -cls.degrees_to_radians(servo_angle)

    # 设置角度（指定转速） / Send angle commands with specified speed
    def set_angle_by_interval(self, size, command_data_list):
        self.uservo.send_sync_multiturnanglebyinterval(
            self.uservo.CODE_SET_SERVO_ANGLE_MTURN_BY_INTERVAL,
            size, command_data_list
        )

    # 查询角度 / Query current servo angle
    def query_servo_current_angle(self, servo_id):
        if servo_id in self.uservo.servos:
            return self.uservo.query_servo_angle(servo_id)

    # 失能舵机 / Disable servo torque
    def disable_torque(self, servo_id):
        self.servo_stop(servo_id)

    # 重设指定舵机多圈圈数 / Reset multi-turn count for a single servo
    def reset_multi_turn_angle(self, servo_id):
        self.uservo.disable_torque(servo_id)
        time.sleep(0.05)
        self.uservo.reset_multi_turn_angle(servo_id)

    # 停止并释放锁力 / Stop servo and release torque lock
    def servo_stop(self, servo_id, mode=2, power=500):
        self.uservo.stop_on_control_mode(servo_id, mode, power)

class Arm_contorl(Node):

    def __init__(self):
        super().__init__(ROBO_DRIVER_NODE)
        self.declare_parameter("robo_type", "robo")

        self.declare_parameter('lock', 'enable')

        self.robo_type = (self.get_parameter("robo_type").get_parameter_value().string_value)
        self.lock = (self.get_parameter("lock").get_parameter_value().string_value)

        try:
            self.Servo = uservo_ex(self.robo_type,log = self.get_logger())
        except ValueError as e:
            raise
        self.target_angle = self.Servo.ZERO_ANGLE
        # self.target_angle 初始目标角度列表 / initial target angle list
        self.interval = [1500 for _ in range(self.Servo.SRV_NUM)]
        self.current_angle = [0.0 for _ in range(self.Servo.SRV_NUM)]
        if(self.lock == "enable"):
            self.arm_move_by_time()
        else:
            self.Servo.disable_torque(0xff)

        # 创建话题：发布joint_states / Create publisher for joint_states topic
        self.joint_states_publisher = self.create_publisher(
            JointState, "joint_states", 10
        )
        # 创建话题：处理设置角度 / Create subscription for SetAngle commands
        self.angle_subscribers = self.create_subscription(
            SetAngle, ROBO_SET_ANGLE_SUBSCRIBER, self.set_angle_callback, 10
        )
        self.timer2 = self.create_timer(0.03, self.timer_callback)
        self.get_logger().info(f"初始化完成 / Initialization complete")

    def node_close(self):
        pass
        # self.Servo.servo_all_stop()

    # 新的执行命令 / Callback for new angle commands
    def set_angle_callback(self, msg):
        for i in range(len(msg.servo_id)):
            id = msg.servo_id[i]
            self.target_angle[id] = int(10*msg.target_angle[i])
            if int(msg.time[i]) < 40:
                (msg.time[i]) = 40
            self.interval[id] = int(msg.time[i])+400

            self.arm_move_by_time()

    # 定时任务 / Timer callback
    def timer_callback(self):
        self.publish_current_angle()

    # 查询舵机角度发布 / Query servo angles and publish
    def publish_current_angle(self):
        JointState_msg = JointState()
        JointState_msg.header.stamp = self.get_clock().now().to_msg()
        JointState_msg.velocity = []
        JointState_msg.effort = []
        self.Servo.uservo.send_sync_servo_monitor(self.Servo.servo_ids)

        for i in range(self.Servo.SRV_NUM):
            self.current_angle[i] = self.Servo.uservo.servos[i].angle_monitor
            JointState_msg.name.append(self.Servo.JOINT_[i])
            JointState_msg.position.append(
                self.Servo.servoangle2jointstate(
                    servo_id=i, servo_angle=self.current_angle[i]
                )
            )
        self.joint_states_publisher.publish(JointState_msg)

    # 默认：控制by时间 / Default control mode: time-based
    def arm_move_by_time(self):
        acc = [0.0 for _ in range(self.Servo.SRV_NUM)]
        for i in range(self.Servo.SRV_NUM):
            acc[i] = int(self.interval[i]/2)
        command_data_list = [struct.pack("<BlLHHH", i, self.target_angle[i], self.interval[i], acc[i], acc[i], 8000) for i in range(self.Servo.SRV_NUM)]
        self.Servo.set_angle_by_interval(self.Servo.SRV_NUM, command_data_list)



def main(args=None):
    rclpy.init(args=args)
    try:
        robo_driver_node = Arm_contorl()
    except Exception as e:
        print(f"[robo_driver] Failed to initialize driver: {e}")
        traceback.print_exc()
        rclpy.shutdown()
        return

    try:
        rclpy.spin(robo_driver_node)
    except KeyboardInterrupt:
        pass
    finally:
        robo_driver_node.node_close()
        robo_driver_node.destroy_node()


if __name__ == "__main__":
    main()

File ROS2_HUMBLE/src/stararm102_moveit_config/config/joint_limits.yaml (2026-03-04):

# joint_limits.yaml allows dynamics properties specified in URDF to be overwritten or augmented as needed

# For beginners, we downscale velocity and acceleration limits.
# You can always specify higher scaling factors (<= 1.0) in your motion requests.  # Increase values below to 1.0 to always move at maximum speed.
default_velocity_scaling_factor: 0.1
default_acceleration_scaling_factor: 0.1

# Specific joint properties can be changed with keys [max_position, min_position, max_velocity, max_acceleration]
# Joint limits can be turned off with [has_velocity_limits, has_acceleration_limits]
joint_limits:
  joint1:
    has_velocity_limits: true
    max_velocity: 3.14
    has_acceleration_limits: false
    max_acceleration: 0
  joint2:
    has_velocity_limits: true
    max_velocity: 3.14
    has_acceleration_limits: false
    max_acceleration: 0
  joint3:
    has_velocity_limits: true
    max_velocity: 3.14
    has_acceleration_limits: false
    max_acceleration: 0
  joint4:
    has_velocity_limits: true
    max_velocity: 3.14
    has_acceleration_limits: false
    max_acceleration: 0
  joint5:
    has_velocity_limits: true
    max_velocity: 3.14
    has_acceleration_limits: false
    max_acceleration: 0
  joint6:
    has_velocity_limits: true
    max_velocity: 13.14
    has_acceleration_limits: false
    max_acceleration: 0
  joint7_left:
    has_velocity_limits: true
    max_velocity: 3.1400000000000001
    has_acceleration_limits: false
    max_acceleration: 0
  joint7_right:
    has_velocity_limits: true
    max_velocity: 3.1400000000000001
    has_acceleration_limits: false
    max_acceleration: 0

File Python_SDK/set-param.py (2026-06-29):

import serial
import struct
import time

BAUDRATE = 1000000
USB = "/dev/ttyUSB2"    # 替换为实际的串口名称
# USB = 'COM3'  # Windows系统下的串口名称

class ServoProtocol:
    
    def __init__(self, port, baudrate=115200, timeout=0.1):
        self.serial = serial.Serial(port, baudrate, timeout=timeout)
        
    def __del__(self):
        if hasattr(self, 'serial') and self.serial.is_open:
            self.serial.close()
    
    def calculate_checksum(self, data):
        return sum(data) % 256
    
    def write_public_parameters(self, 
                               servo_id=0,                      # 舵机ID
                               need_response=0,                 # 控制送出后是否响应
                               baudrate=5,                      # 波特率
                               stall_protection=0,              # 堵转保护开关
                               stall_power_limit=6000,          # 堵转功率上限
                               low_voltage_protection=4000,     # 低电压保护值
                               high_voltage_protection=12600,   # 高电压保护值
                               temperature_protection=735,      # 温度保护值
                               power_protection=20000,          # 功率保护值
                               current_protection=4000,         # 电流保护值
                               startup_force=0,                 # 启动力度
                               hysteresis_percent=80,           # 迟滞百分比
                               power_lock_switch=0,             # 上电锁力开关
                               wheel_mode_brake_switch=0,       # 轮式模式刹车开关
                               angle_limit_switch=1,            # 角度限制开关
                               soft_start_switch=0,             # 上电缓启动开关
                               soft_start_time=3000,            # 上电缓启动时间
                               angle_upper_limit=1800,        # 角度上限
                               angle_lower_limit=-1800):       # 角度下限

        # 构建数据包
        header = bytes([0x12, 0x4C, 0x06, 0x21])

        # 构建参数部分
        params = bytearray([
            servo_id,
            0x01,
            need_response,
            servo_id, 0x00,  # 这个会跟着ID变动
            baudrate,
            stall_protection
        ])
        # 添加堵转功率上限 (2字节，小端序)
        params.extend(struct.pack('<H', stall_power_limit))
        # 添加低压保护电压 (2字节，小端序)
        params.extend(struct.pack('<H', low_voltage_protection))
        # 添加高压保护电压 (2字节，小端序)
        params.extend(struct.pack('<H', high_voltage_protection))
        # 添加温度保护值 (2字节，小端序)
        params.extend(struct.pack('<H', temperature_protection))
        # 添加功率保护值 (2字节，小端序)
        params.extend(struct.pack('<H', power_protection))
        # 添加电流保护值 (2字节，小端序)
        params.extend(struct.pack('<H', current_protection))
        # 添加启动力度
        params.append(startup_force)
        # 添加迟滞百分比
        params.append(hysteresis_percent)
        # 添加上电锁力开关
        params.append(power_lock_switch)
        # 添加轮式模式刹车开关
        params.append(wheel_mode_brake_switch)
        # 添加角度限制开关
        params.append(angle_limit_switch)
        # 添加上电缓启动开关
        params.append(soft_start_switch)
        # 添加上电缓启动时间 (2字节，小端序)
        params.extend(struct.pack('<H', soft_start_time))
        # 添加角度上限 (2字节，小端序)
        params.extend(struct.pack('<H', angle_upper_limit))
        # 添加角度下限 (2字节，小端序)
        params.extend(struct.pack('<h', angle_lower_limit))
        # 添加保留字节
        params.extend([0x00, 0x00])
        # 计算校验和
        checksum = self.calculate_checksum(header + params)
        # 构建完整的数据包
        packet = header + params + bytes([checksum])
        # 发送数据包
        try:
            self.serial.write(packet)
            return True
        except Exception as e:
            print(f"发送数据失败: {e}")
            return False
    
    def write_internal_parameters(self, 
                                 servo_id=0,              # 舵机ID
                                 kp=800,                  # 比例系数
                                 kd=50,                   # 微分系数
                                 ki=0,                    # 积分系数
                                 bias=0,                  # 偏置
                                 hold_kp=800,             # 保持比例系数
                                 hold_kd=50,              # 保持微分系数
                                 hold_bias=0,             # 保持偏置
                                 forward_direction=0,     # 正转方向
                                 dead_zone=1):            # 死区
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

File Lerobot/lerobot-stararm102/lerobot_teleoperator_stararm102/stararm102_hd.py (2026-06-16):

import logging
import select
import sys
import time
from typing import Any

from lerobot.motors import MotorCalibration
from lerobot.processor import RobotAction
from lerobot.teleoperators.teleoperator import Teleoperator
from lerobot.utils.errors import DeviceAlreadyConnectedError, DeviceNotConnectedError

from lerobot_motor_starai.starai import (
    StaraiMotorsBus,
)

from .config_stararm102_hd import Stararm102HDConfig

logger = logging.getLogger(__name__)

MEDIUM_TIMEOUT_SEC = 0.01


class Stararm102HD(Teleoperator):
    """Refactored leader arm integration with optional external button lock control."""

    config_class = Stararm102HDConfig
    name = "stararm102_hd"

    def __init__(self, config: Stararm102HDConfig):
        super().__init__(config)
        self.config = config
        self.bus = StaraiMotorsBus(
            port=config.port,
            motors=config.motors,
            calibration=self.calibration,
            baudrate=config.baudrate,
            position_unit="degrees"
        )
        self.motor_names = self.config.motor_names
        self.button = self.config.button
        self._last_raw_positions: dict[str, float] = {}
        self._last_free_action: RobotAction = {
            f"{motor_name}.pos": 0.0 for motor_name in self.motor_names
        }
        self._leader_locked = self.button.lock_on_connect


    @property
    def action_features(self) -> dict[str, type]:
        return {f"{motor}.pos": float for motor in self.motor_names}

    @property
    def feedback_features(self) -> dict[str, type]:
        return {}

    @property
    def is_connected(self) -> bool:
        return self.bus.is_connected

    def connect(self, calibrate: bool = True) -> None:
        # port and baudrate is exist
        if self.is_connected:
            raise DeviceAlreadyConnectedError(f"{self} already connected")

        logger.info(f"Connecting leader arm on {self.config.port}...")
        self.bus.connect()

        try:
            for motor_name, motor_id in self.config.joint_ids.items():
                if not self.bus.ping(motor_id):
                    raise RuntimeError(f"Servo not found for {motor_name} (id={motor_id}).")
                self._last_raw_positions[motor_name] = 0.0

            if self.button.enabled and not self.bus.ping(self.button.id):
                raise RuntimeError(f"Button servo not found (id={self.button.id}).")

            if not self.is_calibrated and calibrate:
                logger.info(
                    "Mismatch between calibration values in the motor and the calibration file or no calibration file found"
                )
                self.calibrate()

            self.configure()

            if self.button.enabled and self.button.lock_on_connect:
                self._set_locked_state(True)
        except Exception:
            self.bus.disconnect(disable_torque=True)
            raise

        logger.info(f"{self} connected.")

    @property
    def is_calibrated(self) -> bool:
        return bool(self.calibration) and set(self.calibration) == set(self.motor_names)

    def calibrate(self) -> None:
        if self.calibration:
            # Calibration file exists, ask user whether to use it or run new calibration
            user_input = input(
                f"Press ENTER to use provided calibration file associated with the id {self.id}, or type 'c' and press ENTER to run calibration: "
            )
            if user_input.strip().lower() != "c":
                logger.info(f"Writing calibration file associated with the id {self.id} to the motors")
                self.bus.write_calibration(self.calibration)
                return

        self.bus.disable_torque(mode="unlocked")
        logger.info(f"\nRunning calibration for {self}")
        input(
            "\nCalibration: Set Zero Position\n"
            "Please manually move the leader arm to its zero pose and close the gripper.\n"
            "Press ENTER when ready..."
        )

        self.bus.write("Set_Origin", self.motor_names, interval_sec=MEDIUM_TIMEOUT_SEC)
        self.bus.write("Reset_Multi_Turn", self.motor_names)

        homing_offsets = self.bus.set_half_turn_homings()
        print(
            "Move all joints sequentially through their entire ranges "
            "of motion.\nRecording positions. Press ENTER to stop..."
        )
        range_mins, range_maxes = self.bus.record_ranges_of_motion()

        self.calibration = {}
        for motor_name, motor_id in self.config.joint_ids.items():
            self.calibration[motor_name] = MotorCalibration(
                id=motor_id,
                drive_mode=0 if self.config.joint_directions[motor_name] > 0 else 1,
                homing_offset=homing_offsets[motor_name],
                range_min=int(round(range_mins[motor_name])),
                range_max=int(round(range_maxes[motor_name])),
            )

        self.bus.write_calibration(self.calibration)
        self._save_calibration()
        logger.info(f"Calibration saved to {self.calibration_fpath}")

    def configure(self) -> None:
        self.bus.disable_torque(self.motor_names, mode="unlocked")
        time.sleep(MEDIUM_TIMEOUT_SEC)
        self.bus.write("Reset_Multi_Turn", self.motor_names)

    def _read_button_is_locked(self) -> bool:
        angle = self.bus.port_handler.read_servo_angle_monitor(self.button.id)
        if angle is None:
            raise RuntimeError(f"Button servo {self.button.id} has no angle feedback.")
        logger.debug(f"Button servo {self.button.id} angle={float(angle):.1f}")
        return float(angle) >= self.button.trigger_threshold

    def _set_locked_state(self, locked: bool) -> None:
        if locked == self._leader_locked:
            return
        action_name = "lock" if locked else "unlock"
        control_mode = "locked" if locked else "unlocked"
        logger.info(f"Button state changed: {action_name} leader")
        for name in self.config.lockable_motor_names:
            self.bus.port_handler.StopOnControlMode(self.config.joint_ids[name], control_mode, 0)
        time.sleep(MEDIUM_TIMEOUT_SEC)
        self._leader_locked = locked

    @staticmethod
    def _clamp(value: float, min_value: float, max_value: float) -> float:
        """Avoid joint out of range"""
        return max(min_value, min(max_value, value))

    def _compute_action_from_raw(self, raw_positions: dict[str, float]) -> RobotAction:
        action_dict: dict[str, Any] = {}
        for motor_name in self.motor_names:
            range_min, range_max = self.config.joint_ranges[motor_name]
            direction = self.config.joint_directions[motor_name]
            position = raw_positions[motor_name] * direction
            action_dict[f"{motor_name}.pos"] = self._clamp(
                position,
                float(range_min),
                float(range_max),
            )
        return action_dict
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

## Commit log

2026-03-02 feat: init
    [base_link.STL, cello_description.ros2_control.xacro, cello_description.urdf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]
2026-03-04 docs: 更新 StarArm102 机械臂文档和配置
    [base_link.STL, cello_description.ros2_control.xacro, cello_description.urdf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]
2026-03-05 update urdf
    [link1.STL, link2.STL, link3.STL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]
2026-03-05 update normal
    [gazebo_configs.urdf.xacro, ros2_controllers.yaml, stararm102_description.ros2_control.xacro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]
2026-04-16 docs: add hardware documentation and update README
    [Star Arm 102-LD_BOM.xlsx, Star Arm102-LD.DWG]
2026-04-24 update: 更新新的模型
    [base_link.STL, link1.STL, link2.STL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]
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2026-06-30 docs: update hardware resources
    [First-Person_Camera_Mount_Base.STEP, First-Person_Camera_Mount_Top_Cover.STEP, StarArm102_Base_Bottom.STEP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]
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2026-09-03 修正中文 readme 的落地页和购买页入口
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2026-09-06 docs: establish the Star Arm 102 ecosystem hub
    Add Ecosystem and Related Repositories sections linking the four component repositories and the official Star Arm 102 series page. Provide a direct README.zh.md language entry while preserving the existing English and Chinese technical and business content.
    Validation: exact hub and landing-page URLs, four reverse repository links, independent language pages, and README-only scope checked.
2026-09-06 docs: unify Chinese README series overview URL
    Point the Chinese series overview to the canonical fashionstar.com.hk Star Arm 102 landing page, matching Ecosystem and Related Repositories. Preserve mainland product and website links, anchor text,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
    Validation: one URL occurrence changed; all three series landing links now match; purchase and repository links are unchanged.
2026-10-10 Update arm files (#5)
    * 123
    * Delete 123.txt
    * addSTL
    * 删除 link3_V2(test).3mf
    * Add new file 123 with initial content
    * 删除 123
    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
    [star-arm-102-fl-assembly-export-2026-10-08.step, star-arm-102-fl-assembly-export-2026-10-10.STEP, star-arm-102-ld-hd-assembly-export-2026-10-08.step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]
2026-10-10 Use model-specific names for LD and HD assembly STEP files
    Rename the LD and HD assembly exports to identify their respective models. Both files retain identical contents; local documentation link checks passed.
    [star-arm-102-hd-assembly-export-2026-10-10.STEP, star-arm-102-ld-assembly-export-2026-10-10.STEP]
2026-10-10 Remove redundant completion notices from assembly guides
    Remove maintenance status sentences from the LD, HD and FL English and Chinese assembly guides. Preserve assembly instructions, HD servo substitution guidance and video links. Documentation links and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
2026-10-13 Consolidate assembly and calibration guides under docs
    Merge power and wiring instructions into bilingual Get Started guides. Consolidate model assembly videos, HD button wiring, zero calibration and PID setup into one bilingual DIY guide with a two-colu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
    Move guide images, update incoming links and repository trees, and keep English/Chinese directory navigation consistent. PID values, calibration procedures and the camera assembly video remain explic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
    Validation: 69 Markdown link checks, 15 bilingual README checks, 7 Python entry tests, staged whitespace check, and local video-layout preview passed.
2026-10-13 Update hardware step and CAD files (#7)
    Encrease
    1. Step assembly files with a flexible gripper
    2. Camera module and Flexible gripper CAD files in pdf and DWG
2026-10-14 Repair UC-01 terminal surfaces and add BOM cable photos
    Rebuild the KF301 terminal housing markings to close its open surface
    boundaries in the LD, HD and FL UC-01 parts and main assemblies. Preserve
    other STEP entities, assembly placements, hierarchy and color records.
    Add the supplied 120 mm and 200 mm cable photos to all three bilingual
    BOMs, with links to the full-size shared images.
    Validation: all six repaired STEP files reimport in FreeCAD with valid
    shapes and no open shells; terminal bounds and other components are
    unchanged. The seven terminal shells convert to valid solids. Existing
    strict geometry diagnostics elsewhere are not resolved by this change.
    Documentation link and bil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
2026-10-14 Clarify hardware BOM specifications and add verified SKUs
    Add the SKU column after item numbers in all three bilingual BOMs.
    Populate 61 item entries from supplied Excel BOMs and leave 27 uncertain
    entries blank, with matching values in English and Chinese.
    Move printed-part wall loops and infill density into Description, remove
    servo firmware notes, clarify both cable lengths and conductor construction,
    and add the supplied UK-01 board image to the HD BOM.
    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
2026-10-14 Clarify screw head types and locknut names in hardware BOMs
    Synchronize LD, HD and FL English/Chinese fastener descriptions:
    - Specify socket-head cap screws for M3 x 22 and M2 x 8.
    - Correct M2 x 4.5 to Phillips pan head with pre-applied threadlocker.
    - Retain PB2.0 x 5 and remove its unconfirmed countersunk head claim.
    - Describe the 3 x 12 mm self-tapping screw as Phillips flat head, silver finish.
    - Normalize Chinese M3 locknut names and separate surface finish.
    Preserve all SKUs, quantities and image placeholders.
    Validation: check_docs.py (69 files), check_readme_sync.py (15 pairs),
    manual bilingual diff review and git diff --check all passed.
2026-10-14 Simplify hardware BOM columns and clarify remaining screw descriptions
    Remove the Notes column from all three English/Chinese hardware BOMs.
    Preserve regional 3MF settings hints in Description and remove repetitive
    installed-part labels.
    Specify M3 x 10 socket-head cap screws with property class 12.9 and black
    finish. Normalize M2 x 10 hex socket screw names and black finish without
    asserting an unconfirmed head shape. Preserve SKUs, quantities and images.
    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
2026-10-14 Identify PH2.0 servo cables and put finish first in BOM descriptions
    Update both cable lengths in all three bilingual hardware BOMs with PH2.0
    names and connector descriptions, retaining PH-3Y, reversed pin order,
    conductor construction and lengths. Update image alt text accordingly.
    Put color/finish first in fastener and cable descriptions, and normalize
    the Chinese M3 x 10 Phillips screw name. Keep SKUs, quantities and image
    paths unchanged.
    manual bilingual review and git diff --check passed.
    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
2026-10-14 Separate BOM part names and specifications and add screw illustrations
    Split the LD, HD and FL bilingual BOMs into part name, model/specification,
    image, description and quantity columns, with SKU last for customer reading.
    Keep existing quantities and SKU values, and remove duplicated specification
    text from descriptions.
    Add five shared AI-generated screw illustrations with enlargement links and
    an illustration notice. Leave the three unconfirmed head types pending.
    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
2026-10-14 Correct fastener types and washer specifications in hardware BOMs
    Synchronize all three English and Chinese BOMs: identify M3 x 10 Phillips pan heads and M2 x 10 socket heads, replace locknuts with ordinary M3 nuts, and specify stainless steel M3 washers measuring 3 x 6 x 0.5 mm. Quantities and images are unchanged. Validated check_docs.py, check_readme_sync.py and staged diff whitespace.
2026-10-14 Sort BOM fasteners and complete their illustrations
    Group socket-head and Phillips screws by descending length, followed by
    nuts and washers, across all three bilingual hardware BOMs. Preserve
    quantities and renumber the reordered items.
    Add five shared fastener illustrations, identify PB2.0 x 5 as pan-head,
    and depict blue pre-applied threadlocker on the lower two-thirds of the
    M2 x 4.5 screw threads with matching English and Chinese descriptions.
    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
2026-10-15 Correct fingertip orientation and reduce M2 screw thumbnail scale
    Render the FL left fingertip flipped about its horizontal axis to keep the tip facing outward. Reduce the M2 x 4.5 screw subject relative to PB2.0 x 5 while preserving blue threadlocker and the square canvas. Shared assets update both language versions.
    Validation: visual review, check_docs.py, check_readme_sync.py and git diff --check passed.
2026-10-15 Expand bilingual LeRobot guides and replace UC-01 STEP parts
    Organize the customer LeRobot workflow from setup and calibration through
    recording, replay, ACT training, and evaluation. Add synchronized Chinese
    guides, separate developer reference material, and update existing entry
    links while keeping the released ACT model in its compatible environment.
    Replace the UC-01 part in LD, HD, and FL with the supplied STEP file and
    standardize all three filenames as UC-01.step. All copies match the source
    SHA-256; assembly STEP files are unchanged.
    Validation: documentation links (71 files), bilingual structure (17 pairs),
    42 Bash blocks, and 7 Python entry tests pass. Real-hardware end-to-end
    Le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
2026-10-15 Expand ROS 2 guides for planning, simulation and teaching
    Provide synchronized English and Chinese task-based entry points for
    MoveIt virtual/real arms, Gazebo Classic, and hand-guided recording/replay.
    Document setup, expected results, mode transitions, interfaces and
    troubleshooting. Use the combined Gazebo launch to avoid duplicate starts.
    Keep ROS build and hardware validation explicitly pending, and document
    the existing real-gripper action mismatch without changing driver code.
    Validation: local links across 71 Markdown files, 17 bilingual README
    pairs, 38 Bash snippets, section anchors, launch targets and whitespace
    checks pass. Local preview reviewed; no ROS host or physical-arm te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
2026-10-15 fix: correct gripper control and URDF loading
2026-10-16 Fix gripper direction in bag recorder
2026-10-18 docs: clarify servo ID mapping and synchronize bilingual guides
    Add the joint-to-servo ID quick reference to Getting Started and a bilingual
    software-name mapping, linked from hardware, DIY and integration guides.
    Keep servo IDs 0-6 and distinguish the HD button board at ID 7.
    Synchronize Python and historical LeRobot instructions, correct translation
    omissions and paths, and update both ROS 2 guides for the current gripper
    launch override without claiming hardware validation.
    Extend bilingual checks beyond READMEs and add regression coverage.
    Validation: 72 Markdown files pass local-link checks; 21 bilingual pairs
    pass structural checks; 4 documentation-checker tests pass; staged diff
    pa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
2026-10-19 fix(hardware): update Link3 print projects to one plate and one part
    Replace the LD, HD, and FL standalone Link3 3MF projects with the supplied revision while preserving existing filenames. Retain the original single-part plate and remove the extra plate and off-plate instances. Preserve mesh geometry and regional print modifiers.
    Validation: ZIP integrity and XML structure checked; each project contains one plate and one Link3 instance; all three SHA-256 hashes match; local preview downloads verified.
2026-10-19 fix(hardware): restore previous Link3 3MF files
    Restore the LD, HD, and FL standalone Link3 print projects to the version used before the October 19 update, matching the October 18 repository data. Preserve existing filenames.
    Validation: all three files match the pre-134b1cf Git blobs byte-for-byte; archive integrity and local preview downloads verified.
2026-10-19 docs(hardware): clarify BOM fasteners and correct blunt-point illustration
    Synchronize LD, HD, and FL English and Chinese fastener names. Clarify pan head machine screws and countersunk self-tapping screws, replace the supplier PB2.0 designation with 2 x 5 mm, and record confirmed pointed or blunt tips. Add the corrected blunt-point illustration while preserving item numbers and quantities.
    Validation: check_docs.py and check_readme_sync.py passed; bilingual specifications, image references, and unchanged quantities verified.
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2026-10-21 fix(hardware): publish optimized LD assembly and align resource names
    Replace the LD assembly with the organized 2026-10-20 STEP after duplicate wireframe cleanup; retain component placement, groups and styling. Keep the unresolved small handle solid unchanged.
    Normalize LD bearing and servo STEP filenames, update the Link 6 entry in the 12-part STL ZIP, and synchronize bilingual BOM naming and handle-support descriptions. Production STL payloads are unchanged.
    Validation: prior FreeCAD comparison passed for 21 components (220 solids, 12003 faces); staged assembly matches the validated optimized file byte-for-byte; ZIP entries match all 12 directory STLs; documentation and bilingual checks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
2026-10-22 修复四个装配体 STEP 的结构写入位置：新实体必须放在 DATA 段内
    - 上一提交把新增的产品/装配结构写到了 ENDSEC 之后，读取器只解析 DATA 段，导致所有零件丢失装配位置（各自堆在局部坐标）
    - 现在改为插入到 DATA 段末尾的 ENDSEC 之前，文件以 ENDSEC; / END-ISO-10303-21; 正常结束
    - 验证（FreeCAD 装配读入，整体包围盒与原文件一致）：LD/HD 160.00x183.68x282.30，FL 160.00x337.68x309.58，FL 柔性 160.00x337.68x335.47
    - 叶级 21/30/33/37 个零件的实体数、面数、世界包围盒与改前逐件一致，引用零悬空
    - 柔性夹爪装配的 link2 仍为新模型（285 -> 256 面）
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2026-10-23 修正 HD/FL/FL 柔性夹爪装配体的舵机实例命名（每个产品一份独立几何表示）
    - 原因：同名舵机的多个实例共用了同一个 ADVANCED_BREP_SHAPE_REPRESENTATION，导入器按几何表示命名，于是 HD 的 J2/J3/J4 全显示成 J4（带 001/002 后缀）、J6/J7 全显示成 J7（Handle），FL 的 J4 显示成 J7（Gripper）
    - 处理：把被共享的几何表示各复制一份并重新指向（HD 4 处、FL 2 处、FL 柔性 2 处），产品名仍为 J1..J7 + ID0..ID6，顺序与 LD 一致
    - 校验：FreeCAD 导入后七个舵机各自对应自己的 15-16 个实体、位置不再重叠；叶级 34/34（HD、FL）、38/38（FL 柔性）实体数与面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
2026-10-26 docs(hardware): update servo horn images
    Replace servo BOM images for LD, HD, and FL to show the secondary servo horns. Update the English and Chinese BOM references together.
    Validation: check_docs.py, check_readme_sync.py, and git diff --check passed.
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2026-10-31 fix(hardware): match cable full-size images to BOM thumbnails
    Use the existing diagonal 120 mm and 200 mm cable images for click-through links in all LD, HD and FL English and Chinese BOMs. Local documentation link and bilingual structure checks passed; verified the enlarged image in the local preview.
2026-11-01 fix(hardware): align assembly labels and expand FL accessory BOMs
    Correct LD/HD finger-ring labels and document the operator reference with
    orientation diagrams. Refresh printed-part renders using the agreed view.
    Separate the HD UK-01 board from the printed button cover and remove the
    confirmed unused handle solid, preserving the remaining geometry and placements.
    Keep the existing UC-01 shell and intentional J1 configuration unchanged.
    Update the four STEP filenames and internal labels to 2026-11-01. Rename FL
    standard fingertips and all seven flexible-gripper components; give identical
    link instances distinct STEP identities so FreeCAD preserves their labels.
    Add bilingual FL flexible-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
2026-11-02 fix(hardware): correct FL servo to RX8-U48H-M
    Update the first 102-FL servo model and torque to RX8-U48H-M and 48kg-cm in both BOM languages. Replace the photo used for the thumbnail and full-size view, removing the superseded image. Validation: check_docs.py and check_readme_sync.py passed.
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2026-11-10 fix(hardware): match 102-FL URDF link masses to the 865 g assembled arm
    The 102-FL link masses summed to 485 g against the 865 g assembled
    weight. Rebuild each link from the component weight breakdown Fashion
    Star shared on 2026-11-09: servo weights on the link each servo body
    mounts to, printed parts by location, and the 85 g of cables, screws
    and board spread in proportion. Inertia tensors are scaled with each
    link's mass; centres of mass are unchanged.
2026-11-11 fix(hardware): move the 65 g servo to J5 per Fashion Star's clarification
    The 65 g servo drives J5 and the gripper servo is 55 g (Fashion Star,
    11 Nov 2026). link4 goes from 96.5 g to 107.6 g and link6 from 96.5 g
    to 85.4 g; their inertia tensors are rescaled by the same ratio. The
    total stays at 865 g.
2026-11-12 fix(hardware): put the 25 g of base electronics on base_link
    Fashion Star's annotated placement photo (12 Nov 2026) confirms the
    servo-to-link mapping already in this PR and shows 25 g of board and
    cables mounted at the base. That 25 g now sits on base_link; the other
    60 g of cables, screws and connectors stays spread over the links by
    mass. base_link 180.8 g -> 200.5 g, the other links about 3 percent
    lighter, total still 865 g. Inertias rescaled by the same ratios.

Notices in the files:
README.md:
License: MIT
